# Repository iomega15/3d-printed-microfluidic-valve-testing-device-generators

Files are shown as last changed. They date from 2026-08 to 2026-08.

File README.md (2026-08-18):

# Parametric device generators for a geometry-first 3D-printed microfluidic valve framework

OpenSCAD source for the two test devices used in *"A Geometry-First Design Framework
and Interactive Design Tool for 3D-Printed Microfluidic Valves Using New Photopolymer
Resins."* Both files are self-contained: no `include<>`, no `use<>`, no external
libraries. Open in OpenSCAD and press F6, or render headlessly:

    openscad -o device.stl printability_device.scad

Both files render manifold with no errors and take well under a second.

| File | Device | Used for |
|---|---|---|
| `printability_device.scad` | **Printability Device** — arrays of enclosed rigid channels; the roof bridges two sidewalls with the front and back faces open | Stage I, the printability sweep (manuscript Section 3.1, Figures 3-5) |
| `functionality_device.scad` | **Functionality Device** — the same channel plus an enclosed control chamber above the membrane, open-faced front and back for transmitted-light imaging | Stage II onward, membrane functionality and seat geometry (Sections 3.2-3.4, Figures 6-8) |

`examples/` holds one STL rendered from each file at the committed default parameters,
for anyone who wants the geometry without installing OpenSCAD.

The seat radius and penetration these devices need come from the companion interactive
design tool, kept in its own repository (`microfluidic-valve-design-calculator`) and also
provided in the ESI of the paper.

## Choosing the printer

Both files select the machine the same way, with a 1-based `PRINTER_NUMBER`:

```
PRINTER_NUMBER = 2;                 // 1 = Pro 4K (65 um), 2 = Ultra (32 um)
PRINTER_NAMES              = ["Pro 4K 65um", "Ultra 32um"];
PRINTER_BUILD_PLATE_X_SIZES = [175.49, 120.76];
PRINTER_BUILD_PLATE_Y_SIZES = [ 98.75,  67.94];
PRINTER_PIXEL_SIZES         = [ 0.065,   0.032];
PRINTER_LAYER_THICKNESSES   = [ 0.020,   0.050];
```

The pixel pitch and layer height follow from that choice, so every pixel- and layer-denominated parameter rescales with the
machine and nothing else needs touching. Both files also check what they generate against the selected plate: the printability
array reports its occupied footprint (labels and base plate included) as a percentage of the plate and warns, with the overflow
in millimetres, if it does not fit; the functionality strip reduces the device count to what fits and says so rather than
truncating silently. Geometry outside the plate is clipped or rejected at slicing, so neither failure is loud on its own. Add a printer by appending to each array and selecting its number; an out-of-range
number stops the render with a message naming the machines that are defined. The devices reported in the paper were printed on
the Ultra (`PRINTER_NUMBER = 2`), which is the shipped default.

All dimensions are expressed in **printer pixels** (in-plane) and **print layers**
(vertical), so the geometry ports to another printer by changing only the pixel pitch
and layer height. For the Asiga machine used in the paper, 1 px = 32 um and
1 layer = 50 um.

---

## printability_device.scad

Generates a rectangular array of enclosed channels. Two parameters are swept across the
array so that one print yields a whole design matrix under identical process conditions.

**Channel geometry**

| Parameter | Default | Meaning |
|---|---|---|
| `DEFAULT_intra_cell_posts_gap_X_pixels` | 100 | Channel **width** in px. The paper sweeps 1-20 in steps of 1, then 20-150 in steps of 10. |
| `DEFAULT_post_height_layers` | 5 | Channel **height** in layers (5 layers = 250 um in the paper). |
| `DEFAULT_post_size_x_pixels` | 40 | Half-width of the wall between neighbouring channels. Interior walls are formed by two adjacent posts, so the finished wall is **twice** this value; the two outermost walls are exactly this value. |
| `DEFAULT_post_size_y_pixels` | 40 | Channel length per array cell. Total channel length = this x `array_cells_y`. |
| `array_cells_y` | 4 | Number of rows. With the defaults, channel length = 40 x 4 = 160 px. |

**The sweeps**

Both sweeps are always active. To vary only one, pin the other by setting its `min` and
`max` to the same value.

| Parameter | Default | Meaning |
|---|---|---|
| `SWEPT_A_label` | `"membrane_thickness_layers"` | Quantity swept along the columns. |
| `SWEPT_A_min` / `SWEPT_A_max` / `SWEPT_A_step` | 1 / 10 / 1 | Roof (membrane) thickness, 1-10 layers = 50-500 um. |
| `SWEPT_B_label` | `"post_height_layers"` | Quantity swept along the rows. |

Base thickness and the engraved labels can be edited directly; they do not affect the
measurement.

---

## functionality_device.scad

Adds the pneumatic control chamber above the membrane, and the optional raised seat
("doormat") with its spherical recess. `THROUGH_CHANNEL = true` selects the open-faced
form used in the paper, in which the flow channel runs clear through both Y faces so the
lumen can be imaged in transmitted light. `DEBUG_ARRAY_MODE` switches between a single
device and a strip of devices.

> **Legacy naming.** Several parameters are still called `default_cutout_*` for
> historical reasons. They set the dimensions of the **flow channel**, not of a cutout
> pocket; the blind-pocket ("cutout") variant this file grew out of has been retired.

**How many devices, and at what widths**

`DEBUG_ARRAY_MODE = 1` renders one device at the defaults below. `DEBUG_ARRAY_MODE = 0`
renders a strip, and the strip is defined by the width range rather than by a device
count: set the range and the interval, and the number of devices follows.

| Parameter | Default | Meaning |
|---|---|---|
| `WIDTH_SWEEP_ENABLE` | `true` | Drive the strip from the width range below. Set `false` to fall back to the generic `swept_param_1_*` sweep capped by `MAX_DEVICES_X`. |
| `WIDTH_MIN_PX` | 110 | Narrowest channel in the strip. |
| `WIDTH_MAX_PX` | 140 | Widest channel in the strip. |
| `WIDTH_STEP_PX` | 10 | Interval between neighbouring devices. |

So 60 / 120 / 10 emits seven devices at 60, 70, 80, 90, 100, 110 and 120 px, each
engraved with its own width (`CX60`, `CX70`, ...). If the range does not divide evenly
by the interval the last device stops short of `WIDTH_MAX_PX` and the console says so.
If the strip will not fit the build plate, the count is reduced and that is reported too
-- generate wide sweeps in batches.

**Devices are always emitted as a single row, and there is no row-count parameter.**
The lumen is imaged in transmitted light *through* the device along Y, so a device
placed behind another sits in its optical path and neither can be read. Butting devices
together along X is harmless, since nothing is imaged through X, so the whole sweep goes
there. To print more devices than fit one plate, run the width range in batches.

**Flow channel**

| Parameter | Default | Meaning |
|---|---|---|
| `default_cutout_x_size_in_pixels` | 150 | Channel width in px, used for the single-device mode and whenever the width sweep is off. The paper's valves run 60-120 px. |
| `default_cutout_y_size_in_pixels` | follows X | Channel length. With `SQUARE_CUTOUT` it tracks the width, which keeps the imaged region square. |
| `default_cutout_z_size_in_layers` | 5 | Channel height in layers: 5 for a plain square channel, 20 for doormat designs, so that the open gap above the doormat is again 5 layers. |

**Control chamber**

| Parameter | Default | Meaning |
|---|---|---|
| `default_membrane_cavity_x_pixel_multiple` | 170 | Chamber width. The paper uses channel width + 20 px. |
| `default_membrane_cavity_y_pixel_multiple` | 250 | Chamber length. |
| `MEMBRANE_CAVITY_Z_LAYERS` | 12 | Chamber height in layers. |

In through-channel mode the chamber can never exceed the lumen in Y: the block depth is
the chamber depth plus two wall pads while the lumen spans the whole block, so raising
the Y multiple simply grows the whole device.

**Valve seat**

`ENABLE_DOORMAT` and `DOORMAT_SPHERE_RADIUS` are independent, and all four combinations
build one of the geometries in Figure 10 of the paper:

| `ENABLE_DOORMAT` | `DOORMAT_SPHERE_RADIUS` | Geometry |
|---|---|---|
| `true` | > 0 | Raised doormat with a spherical recess in its top (Fig 10-CENTRE). **The configuration the paper characterises** -- every reported leak, burst and lifetime figure comes from it. |
| `true` | 0 | Plain raised doormat, no recess. |
| `false` | > 0 | Recess cut straight into the channel floor, no raised feature (Fig 10-RIGHT), removing the in-channel obstruction. Hypothesised in the paper but not built there. |
| `false` | 0 | Plain channel, no seat. |

**The seat derives itself from the closure model.** `DOORMAT_SPHERE_RADIUS = -1` (the default) computes the recess
radius and depth per device from `KAPPA`, the open lumen left above the seat, and that device's channel width, using the same
closed form the interactive design tool solves. The recess therefore spans the lumen by construction and rescales correctly
across a width sweep. A positive radius overrides the model with a fixed value in mm, which does *not* scale -- use it only to
reproduce a specific historical print. `0` removes the recess.

| Parameter | Default | Meaning |
|---|---|---|
| `KAPPA` | 0.075 | Membrane deflection coefficient s/C for **your** resin and process. Required only when the seat is derived. The default is the value measured for single-layer NanoClear membranes in the paper and will not transfer to another material. |

**In derived mode the control chamber is sized by the model too.** The closure model returns C, the width the deflected
membrane must have; the chamber is what clamps the membrane, so the chamber width is set to C rather than to
`cutout + MEMBRANE_MARGIN_PX`. That makes the arc's chord at the membrane plane coincide with the chamber walls, which is the
geometric condition the seat is solved for. It also makes the device a little wider than the fixed-margin version, and the
width follows the sweep. With an explicit radius the chamber falls back to the margin rule.

**You do not need `KAPPA` to start.** Print with `ENABLE_DOORMAT = false` -- a plain channel, no seat -- measure the sagitta
across a range of widths, and fit the slope: that measurement *is* kappa. Only then does the seated geometry mean anything,
which is why a derived recess is tied to the doormat being enabled. The console prints the full derivation per device (sagitta,
membrane width, radius, depth in mm and in layers) and warns if the required depth exceeds the seat thickness, which means the
doormat is too thin to contain the recess.

`DOORMAT_SPHERE_PENETRATION` is measured down from whichever surface carries the seat --
the doormat top when the doormat is on, the channel floor when it is off -- so a 0.5 mm
recess is 0.5 mm deep either way. The console states which of the four it built on every
render.

| Parameter | Default | Meaning |
|---|---|---|
| `DOORMAT_X_PIXELS` | `-1` | *(doormat only)* Seat width across the channel. **`-1` means match the lumen**, so the seat follows the width sweep automatically -- a 110 px device gets a 110 px seat. A positive value pins the seat to that fixed width on every device instead, which is only what you want if you deliberately need a seat narrower than the channel. With the default, looking through the lumen at seat height shows no opening: that is correct, the flow path runs *over* the seat, which is shorter than the channel is tall. |
| `DOORMAT_Y_PIXELS` | 72 | Seat length. |
| `DOORMAT_THICKNESS_LAYERS` | 3 | Seat height. Set it to `channel height - 5` layers to leave a 5-layer opening above the seat. |
| `DOORMAT_RAMP_ANGLE` | 45 | Chamfer on the seat edges: 45 for the plain doormat, 0 for the cut valve seat. |
| `DOORMAT_SPHERE_RADIUS` | 0.5 | Radius of the spherical recess cut into the seat, in mm. **0 disables the recess.** |
| `DOORMAT_SPHERE_PENETRATION` | 0.5 | Depth of that recess, in mm. |

The radius and penetration are not free parameters: they come from the interactive
design tool in the ESI, evaluated for the resin, printer and channel width in use. For
the framework reported in the paper a 60 px channel takes an effective sphere radius of
64.5 px with 0.25 um penetration. **A different printer, resin or exposure setting gives
different values** -- that is the entire point of measuring the membrane deflection
coefficient first.

---

## Reproducing the paper's devices

1. Set the pixel pitch and layer height to your printer.
2. Print the printability array and classify the channels to find your own printable
   width and roof-thickness window (Stage I).
3. Print the functionality device across widths inside that window and measure the
   membrane sagitta to fit the membrane deflection coefficient (Stage II).
4. Feed that coefficient into the design tool in the ESI to obtain the seat radius and
   penetration for your target channel, and set `DOORMAT_SPHERE_RADIUS` and
   `DOORMAT_SPHERE_PENETRATION` accordingly (Stage III).

## Licence

[PLACEHOLDER: choose on upload -- CC-BY-4.0 is conventional for CAD geometry, MIT or
BSD-3-Clause if you prefer to treat the .scad as source code.]

## Versioning and citation

Each tagged release here is archived to Zenodo automatically. Zenodo issues two kinds of
DOI: one per version, and one "concept" DOI that always resolves to the newest version.
**Cite the concept DOI** -- that way a later bug fix reaches anyone following the
reference, rather than freezing them on the release that was current at press time.

If you use these files, please cite both the paper and this deposit:

[PLACEHOLDER: paper citation once published]
[PLACEHOLDER: Zenodo concept DOI once the first release is archived]

## Reporting problems

Please open an issue on this repository. Fixes go out as a new tagged release, which
Zenodo archives as a new version under the same concept DOI.

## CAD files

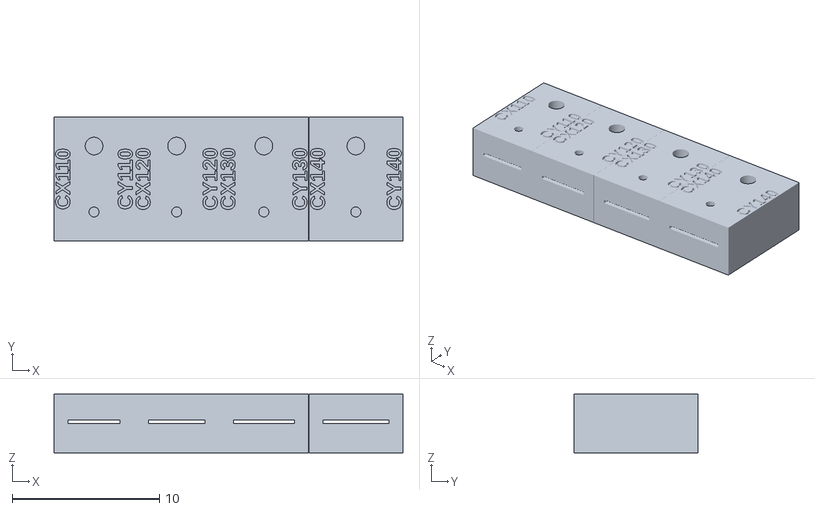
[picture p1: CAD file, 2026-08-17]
examples/functionality_device_default.stl
23.7 x 8.40 x 4.00

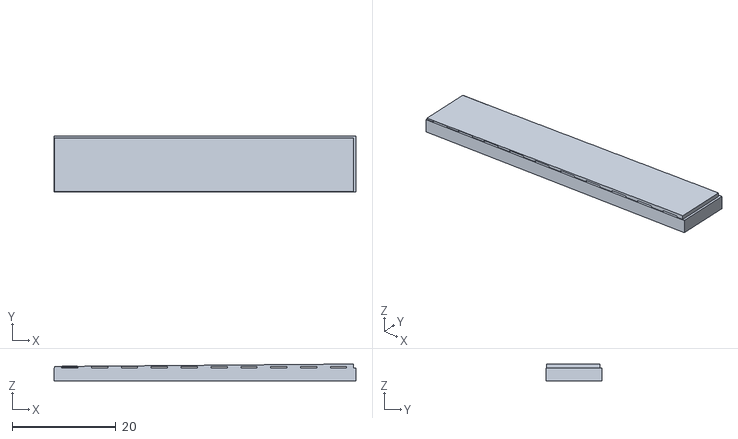
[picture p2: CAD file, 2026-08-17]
examples/printability_device_default.stl
58.2 x 10.9 x 3.25

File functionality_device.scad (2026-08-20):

// ===============================================================================
// MEMBRANE DEVICE — V30 FIXED WITH DOORMAT HALF-VIEW PROPERLY SCOPED
// ===============================================================================
//
// REORGANIZED VERSION - ALL USER INPUTS AT TOP
//
// This version places all user-configurable parameters at the top of the file
// with comprehensive documentation for easy modification.
//
// Fix pack:
// - Half-view cutter ONLY affects doormat visibility, not entire device
// - Y-min/Y-max horizontal ports: epsilon over-travel to prevent coplanar artifacts
// - Doormats properly preserved with correct CSG operations
// - Z-limited pads with z_guard to avoid coplanar faces
// - Higher $fn for smoother cylinders
// - DEBUG_ARRAY_MODE = 1 now shows EXACT user defaults (no parameter sweep)
// - Complete port routing flexibility: all 4 ports independently configurable
// - All membrane cavities maintain TWO ports for effective flushing
// - User-controllable Y-padding thickness overrides (front/back)
// - Diagonal bracing supports under front overhang (print-support-free)
//
// ===============================================================================


// ===============================================================================
// ================================
// DEBUG CONFIGURATION
// ================================
// ===============================================================================

// DEBUG_ECHO: Master debug control - set to true to enable extensive console 
// logging of all dimensions, calculations, and geometry operations. When enabled,
// every major calculation will echo its values to the console for verification.
// Set to false for production to minimize console output.
DEBUG_ECHO = true;

// DEBUG_ARRAY_MODE: Controls how many devices are rendered and with what parameters
//   0 = FULL ARRAY MODE: Renders maximum number of devices that fit on build plate
//       with full parameter sweep (swept_param_1 and swept_param_2)
//   1 = SINGLE DEVICE MODE: Renders exactly ONE device using your exact default 
//       parameters (no parameter sweep). Use this for testing specific configurations.
//   2 = 2x2 GRID MODE: Renders 4 devices (2x2 grid) showing min/max values of 
//       swept parameters. Useful for quick parameter range visualization.
DEBUG_ARRAY_MODE = 0;

// CONFIGURATION_SETTING: Currently set to "solid" for full device rendering.
// This parameter is available for future configuration options.
CONFIGURATION_SETTING = "solid";


// ===============================================================================
// ================================
// USER PARAMETERS - DEVICE CONFIGURATION
// ================================
// ===============================================================================

// ---------------------
// ARRAY SPACING PARAMETERS
// ---------------------
// These parameters control the minimum gap between adjacent devices when 
// rendering arrays on the build plate.

// MIN_GAP_X_MM: Minimum spacing between devices in X direction (mm)
// Ensures devices don't touch and allows for support removal and handling
MIN_GAP_X_MM = 0.01;

// MIN_GAP_Y_MM: Minimum spacing between devices in Y direction (mm)
// Ensures devices don't touch and allows for support removal and handling
MIN_GAP_Y_MM = 0.5;



// ---------------------
// THROUGH-CHANNEL CONFIGURATION  (added for the published device)
// ---------------------
// The devices reported in the paper are imaged in transmitted light, which needs
// an unobstructed optical path straight through the lumen. THROUGH_CHANNEL builds
// the flow channel as a slot that runs the full device depth and opens on BOTH the
// Y-min and Y-max faces, rather than as two blind pockets sharing a back wall.
//
//   true  = one through-channel per device, open front and back (PUBLISHED DEVICE)
//   false = original behaviour: blind pockets alternating front/back face
//
// NOTE: doormat features are cut away by the through-slot, so THROUGH_CHANNEL is
// meant to be used with ENABLE_DOORMAT = false (or a zero-thickness doormat).
THROUGH_CHANNEL = true;

// SQUARE_CUTOUT: force the cutout length (Y) to equal its width (X).
// Every device is then a scaled copy of every other, which is what makes the
// membrane deflection coefficient kappa = s/C a single constant across widths.
// Setting this false lets width and length vary independently, which changes the
// membrane aspect ratio from device to device -- see the paper's limitations section.
SQUARE_CUTOUT = true;

// MEMBRANE_MARGIN_PX: control chamber size = cutout size + this margin, in X and Y.
// Set to -1 to fall back to the explicit membrane-cavity parameters below.
MEMBRANE_MARGIN_PX = 20;

// ---------------------------------------------------------------------------
// CHANNEL-WIDTH SWEEP (drives how many devices are emitted along X)
// ---------------------------------------------------------------------------
// Set the range of channel widths you want and the interval between them; the
// number of devices in the strip follows from that. e.g. 60 -> 120 in steps of 10
// emits seven devices at 60, 70, 80, 90, 100, 110, 120 px, each labelled with its
// own width. This replaces having to work out a device count by hand.
//
// Applies when DEBUG_ARRAY_MODE = 0. A full 1-150 px sweep is slow to render and
// slow to print, so generate the series in batches if you need all of it.
WIDTH_SWEEP_ENABLE = true;
WIDTH_MIN_PX       = 110;   // [px] narrowest channel in the strip
WIDTH_MAX_PX       = 140;   // [px] widest channel in the strip
WIDTH_STEP_PX      = 10;    // [px] interval between neighbouring devices

// MAX_DEVICES_X: only used when WIDTH_SWEEP_ENABLE = false, in which case the strip
// is driven by swept_param_1_* below and capped at this many columns.
MAX_DEVICES_X = 4;

// Devices are always emitted as a SINGLE ROW along X. There is deliberately no
// row-count parameter: the lumen runs clear through both Y faces so it can be imaged
// in transmitted light along Y, which means a device placed behind another sits
// directly in its optical path and neither can be read. Butting devices together
// along X is harmless -- nothing is imaged through X -- so the whole sweep goes there.
// To print more devices than fit one plate, run the width range in batches.

// THROUGH_CHANNEL_Y_PAD_MM: wall left in front of and behind the control chamber.
// In through-channel mode the device depth is set by the CHAMBER (membrane cavity)
// plus this wall on each side -- not by the cutout -- because the chamber is the
// part that has to hold pressure. Too small and the chamber opens onto the face.
THROUGH_CHANNEL_Y_PAD_MM = 0.2;
assert(!THROUGH_CHANNEL || THROUGH_CHANNEL_Y_PAD_MM > 0, "ERROR: THROUGH_CHANNEL_Y_PAD_MM must be > 0 - it alone walls the control chamber off from the Y faces in through-channel mode.");

// ---------------------
// CUTOUT CONFIGURATION
// ---------------------

// num_cutouts_per_face: Number of cutouts on EACH face (front and back)
// Total device cutouts = 2 × num_cutouts_per_face
// Example: If set to 5, device will have 5 front cutouts + 5 back cutouts = 10 total
// Front cutouts are indexed as EVEN numbers (0, 2, 4, 6, 8...)
// Back cutouts are indexed as ODD numbers (1, 3, 5, 7, 9...)
num_cutouts_per_face = 1;

// CREATE_MICROSCOPE_VIEWPORTS: Enable/disable viewing windows on back face
// true = Creates transparent viewing ports above BACK face cutouts for microscopy
// false = Solid material above back cutouts (no viewing access)
// These viewports allow optical access to membrane cavities from above
CREATE_MICROSCOPE_VIEWPORTS = false;


// ---------------------
// CUTOUT STYLE CONFIGURATION
// ---------------------
// Each face can have a different cutout style to optimize for specific use cases

// FRONT_FACE_CUTOUT_STYLE: Style for all FRONT (Y-min) face cutouts
//   "VALVE_SEAT" = Creates cavity with raised doormat feature (elastic membrane seal)
//                  Best for pressure-sensitive applications requiring valve action
//   "SQUEEZE"    = Simple cavity without doormat (flat bottom)
//                  Best for direct compression or simpler membrane mechanics
FRONT_FACE_CUTOUT_STYLE = "VALVE_SEAT";

// BACK_FACE_CUTOUT_STYLE: Style for all BACK (Y-max) face cutouts
//   "VALVE_SEAT" = Creates cavity with raised doormat feature (elastic membrane seal)
//   "SQUEEZE"    = Simple cavity without doormat (flat bottom)
BACK_FACE_CUTOUT_STYLE  = "SQUEEZE";


// ---------------------
// PORT ROUTING CONFIGURATION
// ---------------------
// Each membrane cavity has TWO ports for effective flushing. These parameters
// control where each port exits the device. This allows routing ports away from
// crowded device faces or positioning them for specific experimental setups.

// FRONT FACE PORT ROUTING (for all FRONT/even-numbered cutouts):
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

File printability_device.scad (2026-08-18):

///////////////////////////////////////////////////////////////////////////////

// ================================
// DEBUG CONFIGURATION FLAGS
// ================================
DEBUG_MODE = true;                  // Enable comprehensive debug output
DEBUG_GEOMETRY = true;              // Log geometry calculations
DEBUG_LABELS = true;                // Log label autoscaling calculations
DEBUG_VALIDATION = true;            // Enable runtime validation checks
DEBUG_TEXT_METRICS = true;          // Log text size calculations

// ================================
// USER INPUTS - MODIFY THESE ONLY
// ================================

/* --- PRINTER SELECTION --------------------------------------------------------
   Everything dimensioned in pixels or layers follows from the machine, so pick the
   machine here rather than editing the two constants below. Add a printer by
   appending to each array and selecting its number.
   Same convention as the other generators in this project: PRINTER_NUMBER is
   1-based, so 1 is the first entry in the arrays.                                */
PRINTER_NUMBER = 2;                 // 1 = Pro 4K (65 um), 2 = Ultra (32 um)

PRINTER_NAMES              = ["Pro 4K 65um", "Ultra 32um"];
PRINTER_BUILD_PLATE_X_SIZES = [175.49, 120.76];   // [mm] exact X from the Asiga software
PRINTER_BUILD_PLATE_Y_SIZES = [ 98.75,  67.94];   // [mm] exact Y from the Asiga software
PRINTER_PIXEL_SIZES         = [ 0.065,   0.032];  // [mm/px] XY projector pixel
PRINTER_LAYER_THICKNESSES   = [ 0.020,   0.050];  // [mm/layer] slice height

// Derived -- do not edit. The devices in the paper were printed on the Ultra.
PRINTER_NAME       = PRINTER_NAMES[PRINTER_NUMBER-1];
BUILD_PLATE_X_SIZE = PRINTER_BUILD_PLATE_X_SIZES[PRINTER_NUMBER-1];
BUILD_PLATE_Y_SIZE = PRINTER_BUILD_PLATE_Y_SIZES[PRINTER_NUMBER-1];
PIXEL_SIZE         = PRINTER_PIXEL_SIZES[PRINTER_NUMBER-1];       // [mm/px]
LAYER_THICKNESS    = PRINTER_LAYER_THICKNESSES[PRINTER_NUMBER-1]; // [mm/layer]

assert(PRINTER_NUMBER >= 1 && PRINTER_NUMBER <= len(PRINTER_NAMES),
       str("PRINTER_NUMBER = ", PRINTER_NUMBER, " but only ", len(PRINTER_NAMES),
           " printers are defined (1 = ", PRINTER_NAMES[0], ", 2 = ", PRINTER_NAMES[1],
           "). Pick one of those, or append a new machine to each PRINTER_* array."));

echo(str("=== PRINTER: ", PRINTER_NAME, " === build plate ", BUILD_PLATE_X_SIZE, " x ",
         BUILD_PLATE_Y_SIZE, " mm | ", PIXEL_SIZE, " mm/px | ", LAYER_THICKNESS,
         " mm/layer"));

/* --- Array layout --- */
array_cells_x     = 10;              // [count] columns (X)
array_cells_y     = 4;              // [count] rows (Y)

/* --- Safety buffers (outer-to-outer clearances during compact packing) --- */
safety_buffer_x_pixels = 0;         // [px] horizontal buffer added between columns
safety_buffer_y_pixels = 0;         // [px] vertical buffer added between rows

// Add near top with other constants
//OVERLAP_MM = 0.002;  // [mm] tiny overlap for seamless fusion when buffer=0


/* --- Rectangular post geometry (defaults, before sweeps) --- */
DEFAULT_post_size_x_pixels = 40;     // [px] sx baseline (X width of a post)
DEFAULT_post_size_y_pixels = 40;     // [px] sy baseline (Y depth of a post)
DEFAULT_post_height_layers = 5;     // [layers] post height

/* --- Intra-cell gaps (defaults, before sweeps) --- */
DEFAULT_intra_cell_posts_gap_X_pixels = 100  ; // [px] gap between left/right post pairs (X)
DEFAULT_intra_cell_posts_gap_Y_pixels = 0; // [px] gap between bottom/top post pairs (Y)

/* --- Membrane (inner film, drawn on top of posts) --- */
DEFAULT_membrane_Z_thickness_layers = 1;   // [layers] (0 disables membranes)
// Fractional overlap into posts (0 = only void; >0 intrudes into posts)
DEFAULT_membrane_post_coverage_x  = 1;     // [fraction of sx] along X
DEFAULT_membrane_post_coverage_y  = 1;     // [fraction of sy] along Y



/* --- Two-Selector, Unit-Aware Sweeps (SWEPT) ---
   Choose any TWO labels (one per selector). Native units per label:
   
   Absolute (sets parameter directly):
     • "post_size_x"                                 [px]
     • "post_size_y"                                 [px]
     • "intra_cell_post_gap_x"                       [px] (gap between cell columns (X))
     • "intra_cell_post_gap_y"                       [px] (gap between cell rows (Y))
     • "membrane_post_coverage_x"                    [0 to 1 fraction]
     • "membrane_post_coverage_y"                    [0 to 1 fraction]
     • "membrane_thickness_layers"                   [layers]
     • "post_height_layers"                          [layers]
     • "cell_aspect_ratio_post_Z_to_cell_gap_X"      [layers/px]  (post_Z : gap_X) - 2nd swept variable must be one of the variables in this ratio to make senes, otherwise nothing will be swept over 
     • "cell_aspect_ratio_post_Z_to_cell_gap_Y"      [layers/px]  (post_Z : gap_Y) - 2nd swept variable must be one of the variables in this ratio to make senes, otherwise nothing will be swept over
   
   Coupled / scale (unitless ratio; multiplies parameters relative to their DEFAULTs):
     • "post_size_scale_both_xy"                     [fraction]
     • "intra_cell_post_gap_scale_both_xy"           [fraction]
     • "membrane_post_coverage_both_xy"              [fraction]
       (special handling: if the default coverage is 0, the scale is
        interpreted as an ABSOLUTE coverage value in [0,1])

   NEW Coupled aspect-preserving scalers (unitless ratio; multiplies DEFAULTs):
     • "post_Z_and_cell_gap_X_scale_both"            [ratio]  // scales DEFAULT_post_height_layers and DEFAULT_intra_cell_posts_gap_X_pixels together
     • "post_Z_and_cell_gap_Y_scale_both"            [ratio]  // scales DEFAULT_post_height_layers and DEFAULT_intra_cell_posts_gap_Y_pixels together

   Sweep A varies by COLUMN (cx); Sweep B varies by ROW (cy).
   If a selector is not used, set its label to "".
   If both selectors target the same label, the cell uses MAX(base, A, B).
*/
SWEPT_A_label = "membrane_thickness_layers";  // "", or any label above
SWEPT_A_min   = 1;                     // native unit of SWEPT_A_label
SWEPT_A_max   = 10;                    // native unit of SWEPT_A_label
SWEPT_A_step  = 1;                    // per-column increment

SWEPT_B_label = "post_height_layers";  // "", or any label above
SWEPT_B_min   = 5;                     // native unit of SWEPT_B_label
SWEPT_B_max   = 5;                     // native unit of SWEPT_B_label
SWEPT_B_step  = 1;                     // per-row increment

/* --- Edge Labels (optional) ---
   Right (Xmax) explains rows / Sweep B
   Top   (Ymax) explains columns / Sweep A */
enable_edge_labels           = false;                 // show labels?
edge_label_style             = "indented";             // "raised" | "indented"
edge_label_font              = "Liberation Sans";    // installed font

// AUTOSCALING: These are NOT used directly - text size is calculated automatically
edge_label_thickness_mm      = 0.2;                 // raised thickness (mm)
edge_label_indent_mm         = 0.2;                 // indent depth (mm)

// Space allocated for labels (in pixels - converted to mm internally)
label_margin_right_pixels    = 10;   // [px] space on +X (for ROW label / Sweep B)
label_margin_top_pixels      = 10;   // [px] space on +Y (for COL label / Sweep A)

// Minimum gap between array and text (safety margin)
label_safety_gap_mm          = 0.1;  // [mm] minimum gap between array and text

/* --- Base plate (optional) --- */
draw_base_plate         = true;
base_plate_thick_layers = 50;      // [layers]

// ================================
// CALCULATED VALUES - AUTO-COMPUTED
// ================================
px = PIXEL_SIZE;                           // [mm/px]
mm_buffer_x = safety_buffer_x_pixels * px; // [mm]
mm_buffer_y = safety_buffer_y_pixels * px; // [mm]

post_h_mm = DEFAULT_post_height_layers * LAYER_THICKNESS; // [mm]

label_margin_right_mm = label_margin_right_pixels * px;
label_margin_top_mm   = label_margin_top_pixels * px;

// Echo all calculated base values for debugging
echo("======== CALCULATED BASE VALUES ========");
echo("px (mm/pixel):", px);
echo("mm_buffer_x:", mm_buffer_x, "mm");
echo("mm_buffer_y:", mm_buffer_y, "mm");
echo("post_h_mm:", post_h_mm, "mm");
echo("label_margin_right_mm:", label_margin_right_mm, "mm");
echo("label_margin_top_mm:", label_margin_top_mm, "mm");

// Replace the OVERLAP_MM line with:
OVERLAP_MM = LAYER_THICKNESS;  // Use one layer thickness - guaranteed to merge properly

// And simplify the overlap logic - apply to the SIZE only, not position:
overlap_x = (safety_buffer_x_pixels == 0) ? OVERLAP_MM : 0;
overlap_y = (safety_buffer_y_pixels == 0) ? OVERLAP_MM : 0;
// ================================
// HELPER FUNCTIONS WITH VALIDATION
// ================================

function clamp(x, lo, hi) = min(max(x, lo), hi);
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

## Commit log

2026-08-17 Parametric OpenSCAD generators and interactive design tool for 3D-printed microfluidic valves
    - printability_device.scad: enclosed-channel array for the Stage I printability sweep
    - functionality_device.scad: membrane valve with control chamber, open-faced for
    transmitted-light imaging; width strip driven by WIDTH_MIN/MAX/STEP_PX
    - tool/index.html: interactive geometric closure calculator (kappa-based seat design)
    - README keyed to parameter names; example STLs rendered from the committed defaults
    [functionality_device.scad, functionality_device_default.stl, printability_device.scad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]
2026-08-18 Doormat width defaults to matching the lumen, so the seat follows the width sweep
    DOORMAT_X_PIXELS = -1 (the new default) makes the seat span the full channel
    width, so a 110 px device gets a 110 px seat and a 140 px device a 140 px seat.
    A positive value keeps the previous behaviour: a fixed seat width on every
    device, independent of the sweep. Verified in the mesh: seat top faces measure
    110/120/130/140 px against the matching lumens, and an explicit 40 still pins
    every seat at 1.28 mm.
    A seat narrower than the channel leaves an open bypass down each side, which is
    why matching the lumen is the sensible default.
    [functionality_device.scad]
2026-08-18 Derive the spherical seat from the closure model instead of hard-coded millimetres
    The seat radius and depth are not free parameters: given the open lumen above the
    seat, kappa, and the channel width, the closure model determines them. They are now
    computed per device from the same closed form the design tool solves, so the recess
    spans the lumen by construction and rescales across a width sweep. The old defaults
    (R = 0.5 mm, depth = 0.5 mm) were a 1 mm hemispherical dimple, roughly a twentieth of
    the radius the model asks for at these widths.
    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
    [functionality_device.scad]
2026-08-18 Fix the spherical seat cutting through the device side walls
    The volume bounding the recess was 2x the lumen width, centred on the lumen, so it
    did not confine the recess to the channel at all. That never showed with the old
    0.5 mm dimple, but the derived seat has a radius of 9-11 mm and widens as it rises,
    so above the seat top it was wider than the channel and carved into the solid side
    walls -- measured at up to 0.935 mm into a 0.96 mm wall, and clean through for a
    thicker seat. The bound is now the lumen footprint exactly.
    Also: in derived mode the control chamber width is set to C, the membrane width the
    closure model requires, instead of cutout + MEMBRANE_MARGIN_PX. The membrane is
    cl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
    [functionality_device.scad]
2026-08-18 Make the printer selectable in both generators, with one shared convention
    printability_device.scad had PIXEL_SIZE and LAYER_THICKNESS hard-wired to the Ultra's
    0.032/0.05, with no way to build for another machine. It now carries the same printer
    table as the rest of the project.
    functionality_device.scad already had the table but selected with a 0-based
    SELECTED_PRINTER, so 'printer 1' meant the Ultra there and the Pro 4K elsewhere -- a
    trap with two files in one deposit. Both now use a 1-based PRINTER_NUMBER with
    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
    [functionality_device.scad, printability_device.scad]
2026-08-18 Warn when the printability array does not fit the selected build plate
    The array grows with array_cells_x/y and with the swept ranges, and the base plate adds
    a label margin on each side, so it can outgrow the plate with nothing complaining until
    the slicer clips or rejects it. It now reports the occupied footprint against the plate
    as a percentage and warns with the overflow in millimetres, naming the parameters to
    reduce.
    The reported footprint is the base plate extent, which is the widest thing in the scene
    when it is drawn. Verified against the rendered meshes: 58.24 x 10.88 mm on the Ultra
    and 118.30 x 22.10 mm on the Pro 4K, matching the STL bounding boxes exactly. A 30-column
    array o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
    [printability_device.scad]
2026-08-20 Ship the paper's seated-valve configuration as the default
    Defaults previously carried the bench state: doormat off, half-view
    visualization cut on, and channel/seat heights (5/3 layers) on which the
    derived seat legitimately warns that its depth exceeds the seat. The
    shipped defaults are now the configuration the accompanying paper adopts
    (Section 3.4.1): doormat ON with the kappa-derived spherical recess,
    half-view OFF, a 20-layer channel carrying a 15-layer seat so the open
    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
    [functionality_device.scad]
